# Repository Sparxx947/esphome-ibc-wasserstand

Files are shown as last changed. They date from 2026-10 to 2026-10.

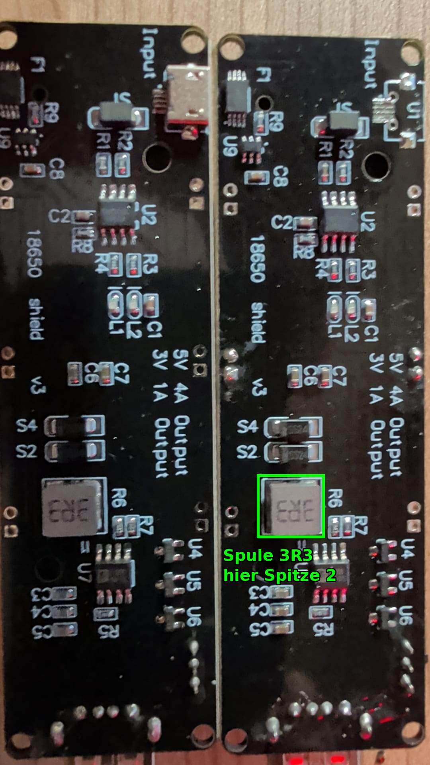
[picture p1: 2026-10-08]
fotos/shield-rueckseite-spule.jpg

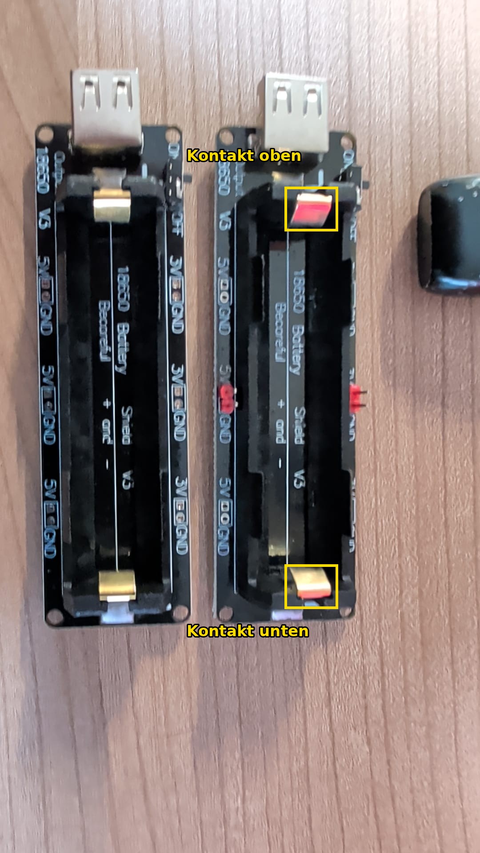
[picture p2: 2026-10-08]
fotos/shield-vorderseite-kontakte.jpg

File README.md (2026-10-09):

🇬🇧 [English version](README.en.md)

# IBC-Wasserstand und Überlaufschutz (ESPHome + Home Assistant)

Füllstandsmessung für einen 1000-l-IBC-Regenwassercontainer mit Pumpensteuerung, damit er nicht überläuft.
Zwei ESPHome-Knoten auf Wemos D1 mini, die Pumpenlogik läuft in Home Assistant.

> **Stand: 08.10.2026.** Quellen: Projektnotizen (04.–08.10.2026), Firmware aus dem ESPHome Builder, SCAD-Dateien, HA-Paketentwurf.
> Was nicht gemessen oder bestätigt ist, steht als *(ungeprüft)* oder *(Annahme)* im Text.

> **Nachbauen:** Die Dateien bilden eine konkrete Anlage ab. Vor eigener Verwendung:
> - Eigene `secrets.yaml` aus [`firmware/secrets.example.yaml`](firmware/secrets.example.yaml) anlegen (WLAN, API-Schlüssel, Fallback-AP-Passwörter).
> - In [`firmware/ibc-b.yaml`](firmware/ibc-b.yaml) unter `manual_ip` eine eigene feste IP eintragen (IP, Gateway, Subnetz, DNS) oder den `manual_ip`-Block entfernen, dann gilt DHCP.
> - In [`ha/ibc-pumpe.yaml`](ha/ibc-pumpe.yaml) die Entitäten-IDs an die eigene Anlage anpassen (Pumpen-Steckdose, Leistungssensor, ESPHome-Entitäten) und `notify.mobile_app_dein_handy` durch den eigenen Notify-Dienst ersetzen.
> - `abstand_leer_mm` / `abstand_voll_mm` (Knoten A) und `adc_faktor` (Knoten B) selbst einmessen, siehe [`docs/einmessen.md`](docs/einmessen.md).

---

## 1. Kurzbeschreibung

**Aufbau vor Ort:** Drei IBC-Container (je 1000 l, auf Palette) stehen ebenerdig draußen unter einem Dach.

| Container | Rolle | Was dort sitzt |
|---|---|---|
| **A** | Sammelbehälter. Zulauf von oben über ein HT-Rohr DN50 (Regenrinne) | Tauchpumpe mittig am Boden (Steigrohr ragt aus dem Einfüllstutzen), **Knoten A `ibc-wasser`** mit Ultraschallsensor auf der Oberseite |
| **B** | Zielbehälter, 2–3 m höher angefahren | **Knoten B `ibc-b`** (Solar, Tiefschlaf) mit Schwimmerschalter im Einfüllstutzen |
| **C** | Zielbehälter | unten per Schlauch mit B verbunden, steht daher gleich hoch wie B, braucht keinen eigenen Sensor |

**Prinzip:**

1. **Knoten A** misst mit einem wasserdichten Ultraschallsensor (A02YYUW, UART) von oben den Abstand zur Wasseroberfläche
   und rechnet daraus Füllstand in % und Inhalt in Litern. Ein IBC ist annähernd ein Quader, deshalb ist die Umrechnung linear
   (≈ 10 l pro cm).
2. **Knoten B** meldet über einen Schwimmerschalter, ob B/C voll sind. Er läuft auf einem 18650-Akku mit kleinem Solarpanel,
   wacht alle 15 min auf und bleibt wach, solange die Pumpe läuft.
3. **Home Assistant** schaltet die vorhandene Pumpe in A über eine Zigbee-Steckdose mit Leistungsmessung:
   an bei A ≥ 90 %, aus bei A ≤ 70 %, sofort aus bei „Ziel voll“. Dazu kommen Sicherungen gegen Trockenlauf, zu lange Laufzeit,
   Ausfall der Sensoren und ein stummer Knoten B.

**Ausfallrichtung:** Ein offener Schwimmereingang, also auch ein abgerissenes Kabel, gilt als „Ziel voll“ und sperrt die Pumpe.
Meldet sich Knoten B nicht, startet die Pumpe nicht. Nach einem Stromausfall bleibt die Steckdose aus.

---

## 2. Status (Stand 09.10.2026)

| Bereich | Status | Datum / Hinweis |
|---|---|---|
| Ultraschallsensor A02YYUW | ✅ geliefert, am Tisch getestet (Zimmerdecke 1,37–1,47 m, Hand sofort erkannt) | 06.10. |
| Knoten A geflasht, im Builder und in HA | ✅ fertig | 06.10. ~20:15 |
| Kombi-Gehäuse A (Sensor + D1 mini) | ✅ gedruckt (2. Fassung, siehe Abschnitt 5) | 07.10. |
| Kabelverschraubungen M12 | 🟡 bestellt (Amazon), Lieferung Fr 09.10.; werden mit Heißkleber eingeklebt | 09.10. 18:00 |
| Montage A auf dem IBC + Einmessen | ⬜ offen | bis 22.10. |
| Schwimmer-Eingang aus Firmware A entfernen | ⬜ offen (beim Einmessen) | — |
| Pumpen-Steckdose (Nous Zigbee) | ✅ in HA, Power-outage-memory = off; **zurzeit ausgesteckt** | 07.10. |
| Knoten B geflasht (feste IP), im Builder und in HA | ✅ fertig, „wach halten“/Tiefschlaf getestet | 07.10. ~21:30–21:45 |
| Knoten B Innenverdrahtung (D0–RST, A0-Teiler, Schwimmer) | ✅ fertig, Tischtest Schwimmer bestanden | 08.10. 17:32 |
| Schwimmerhalter B | ✅ gedruckt | 08.10. |
| Gehäuse B | ⬜ druckfertig, noch nicht gedruckt | — |
| Deckeldichtung B (TPU) | ✅ konstruiert, Kollision geprüft; ⬜ nicht gedruckt | 09.10. |
| Deckelschrauben B 3 × 12 | ⬜ fehlen, kaufen | — |
| Akku B | 🟡 E-Zigarettenakku im Selbstentladetest (Bezug 4,137 V) | Bewertung 09.10. 14:30 |
| Solarpanel, Z-Diode, EVE-Akku, Panelkabel | ⬜ nicht bestellt, reichelt-Bestellung geplant | 02.11. |
| HA-Pumpenpaket `ha/ibc-pumpe.yaml` | ⬜ Entwurf, **nicht eingespielt** (in HA existiert noch keine IBC-Automation) | — |
| Pumpen-Normalleistung, Trockenlauf-Schwelle | ⬜ offen, erst beim ersten Pumpenlauf messbar | — |

---

## 3. Stückliste

Preise und Artikelnummern nur dort, wo sie in den Notizen belegt sind. „—“ = nicht notiert.

### Knoten A (`ibc-wasser`, Container A)

| Teil | Menge | Bezeichnung / Typ | Bezugsquelle, Art.-Nr., Preis | Status |
|---|---|---|---|---|
| Mikrocontroller | 1 | Wemos D1 mini V3.0.0 (ESP8266, USB-Seriell CH340) | Bestand (früheres WLAN-Testgerät) | vorhanden, geflasht |
| Ultraschallsensor | 1 | A02YYUW-Typ, UART 9600, 3–450 cm, wasserdicht (IP67), 60° Abstrahlwinkel; Rechteckgehäuse 84,6 × 29,6 × 18,5 mm (Datenblatt DFRobot SEN0311), Kabel ~32 cm mit JST-PH-Stecker | Amazon B0CM1F4KFS, 21,95 € | geliefert 06.10. |
| Gehäuse + Deckel | 1 + 1 | `ibc_kombi_gehaeuse.stl` + `ibc_kombi_deckel.stl` | Eigendruck, PETG | gedruckt 07.10. |
| Kabelverschraubung | 2 | M12, Klemmbereich 3–6,5 mm, IP67, schwarz (Seki, 10er-Pack, für A und B) | Amazon B083V8V9TR, 5,49 € / 10 Stk | bestellt, Lieferung 09.10. |
| Blechschrauben Befestigung | 4 | Edelstahl 4,2 × 16 (im IBC 3,2 mm vorbohren) | — | *ungeklärt* |
| Blechschrauben Deckel | 4 | 3 × 16 | — | *ungeklärt* |
| Dichtband | 1 | zwischen Flansch und IBC-Oberseite | — | *ungeklärt* |
| Silikon | etwas | Raupe unter dem Sensor und im Kabelschlitz der Trennwand | — | *ungeklärt* |
| Heißkleber | etwas | Gegenmuttern der M12-Verschraubungen innen sichern | — | vorhanden *(Annahme)* |
| Stromversorgung | 1 | langes USB-Kabel, an 5V/G des D1 mini angelötet, plus USB-Netzteil | — | *ungeklärt* |
| Kabelbinder | einige | optional zusätzlich an der Käfigstrebe | — | — |

### Knoten B (`ibc-b`, Container B)

| Teil | Menge | Bezeichnung / Typ | Bezugsquelle, Art.-Nr., Preis | Status |
|---|---|---|---|---|
| Mikrocontroller | 1 | Wemos D1 mini (ESP8266, CH340) | Bestand | vorhanden, geflasht |
| Akku-Shield | 1 | „18650 Battery Shield V3“, **rechte Ausführung** (Input-Buchse U1 nicht bestückt, Diode SS24 vorhanden). Bestückung vermutlich TC4056A + DW01/8205 + FP6298 *(nach Layout abgeleitet, Aufdrucke unlesbar)* | Bestand | vorhanden, Polung geprüft |
| Akku (Variante 1) | 1 | 18650 aus einer E-Zigarette, vermutlich ungeschützte Hochstromzelle | Bestand | im Selbstentladetest bis 09.10. |
| Akku (Variante 2) | 1 | EVE 18650-33V, Flat-Top | reichelt, 6,82 € | nicht bestellt (02.11.) |
| Solarpanel | 1 | Seeed DEBO SOLAR 1.0W, 5,5 V / ~170 mA, **Leerlauf bis 8,2 V** | reichelt, 6,20 € (lieferbar ab 23.10.) | nicht bestellt (02.11.) |
| Z-Diode | 2 (1 + Reserve) | BZX 85C6V2, 6,2 V / 1,3 W | reichelt, 0,06 €/Stk | nicht bestellt (02.11.) |
| Panelkabel | ~3 m | H05RN-F 2 × 0,75 mm² (außen) | reichelt, — | nicht bestellt (02.11.) |
| Widerstände | 2 | 100 kΩ + 22 kΩ in Reihe (gemessen zusammen 121,5 kΩ) | Sortiment | eingebaut 08.10. |
| Drahtbrücke | 1 | D0 (GPIO16) → RST, für den Tiefschlaf | — | eingebaut 08.10. |
| Schwimmerschalter | 1 | seitlicher Einbau-Schwimmer mit Klappschwimmer (Reed, 2 Adern, ~3 mm Kabel), Gewinde Ø 19 mm × 19,5 mm, Dichtring + Mutter; Pfeil am Körper = Einbaulage | Bestand | vorhanden |
| Schwimmerhalter | 1 | `ibc_schwimmer_halter.stl` | Eigendruck, PETG | gedruckt 08.10. |
| Gehäuse + Deckel | 1 + 1 | `ibc_b_gehaeuse.stl` + `ibc_b_deckel.stl` (außen 130 × 74 × 32 mm + Laschen) | Eigendruck, PETG | druckfertig, nicht gedruckt |
| Kabelverschraubung | 2 | M12 aus dem Seki-Pack (s. o.): Schwimmer + Panel | s. o. | bestellt |
| Schrauben Deckel | 4 | 3 × 12, Blech- **oder** Spanplattenschraube (beißt in PETG-Dome mit 2,5-mm-Loch), Edelstahl A2 oder verzinkt | — | fehlen, kaufen |
| Deckeldichtung | 1 | `ibc_b_dichtung.stl`, TPU 95A (~2,8 g). Alternative: selbstklebendes EPDM-Moosgummiband ~3 mm breit, 2–3 mm dick | Eigendruck | konstruiert 09.10., nicht gedruckt |
| Klemme innen | 1 | Schraubklemme/Stecker für Schwimmer und Panel (Verlängerung innen im Gehäuse, nicht draußen) | — | offen |
| Befestigung | — | Kabelbinder (bis 5 mm) oder Schraube 4 mm durch die Laschen an den Käfig | — | — |
| Externe Antenne | — | erst, wenn der WLAN-Test am Standort schlecht ist (Reserve: D1 mini Pro mit Antennenbuchse) | — | bewusst nicht gekauft |

### Pumpe, Steckdose, Sonstiges

| Teil | Menge | Bezeichnung / Typ | Bezugsquelle, Preis | Status |
|---|---|---|---|---|
| Pumpe | 1 | vorhandene Tauchpumpe in A, Steigrohr → Edelstahl-Wellschlauch → Kugelhahn → Gartenschlauch zu B/C. Typ/Leistung **unbekannt** | Bestand | vorhanden |
| Zigbee-Steckdose | 1 | Nous Smart Plug mit Leistungsmessung (Zigbee2MQTT). **Innengerät** → unter Dach bzw. in Schutzbox | Bestand | vorhanden, zurzeit ausgesteckt |
| Verbindung B ↔ C | 1 | Schlauch unten zwischen B und C | Bestand | vorhanden |
| Multimeter | 1 | UNI-T UT139C (µA-Bereich, für Ruhestrom und ADC-Abgleich) | Amazon B00KKLW35O, 49,50 € | bestellt, Lieferung 09.10. |
| Filament | — | PETG (ASA bei direkter Sonne) | Bestand | vorhanden |

> Die alternative 4× Hilpress ECO 50010 aus dem ersten reichelt-Korb ist durch das Seki-Pack ersetzt.
> Die Farbe der Seki-Lieferung ist unsicher: Der Shop beschreibt auch die Variante „Schwarz“ als „grau (RAL7035)“.

---

## 4. Pinbelegung und Verdrahtung

### Knoten A (`ibc-wasser`)

| Von | Ader / Signal | D1 mini | GPIO | Hinweis |
|---|---|---|---|---|
| A02YYUW | rot, VCC | 3V3 | — | an 3,3 V liegt auch der TX-Pegel bei 3,3 V, also ESP-sicher |
| A02YYUW | schwarz, GND | G | — | |
| A02YYUW | weiß, TX (Sensor sendet) | D7 | GPIO13 | UART RX, 9600 Bd, Paket alle ~100 ms: `0xFF, Hi, Lo, Summe` |
| A02YYUW | gelb, RX / Modus | **frei lassen** | — | auf Masse schaltet der Sensor in einen anderen Ausgabemodus |
| USB-Netzteil | +5 V / GND | 5V / G | — | Kabel angelötet, durch eine M12-Verschraubung |
| ~~Schwimmer~~ | ~~2 Adern~~ | ~~D5 + G~~ | ~~GPIO14~~ | **entfällt**, der Schwimmer sitzt jetzt an Knoten B. Steht noch in der Firmware und wird beim Einmessen entfernt |

Die Aderfarben stammen aus dem Werkstattbuch und sind gegen den gelieferten Sensor nicht gesondert dokumentiert. Vor dem Anlöten bitte nachsehen.

### Knoten B (`ibc-b`) – Schaltplan: [`plaene/ibc-b-schaltplan.pdf`](plaene/ibc-b-schaltplan.pdf)

| Von | Nach | Hinweis |
|---|---|---|
| Solarpanel + | Z-Diode Kathode (Ring) → Shield-Pads U1 **VBUS** | Z-Diode **parallel** zum Eingang. Vor dem Löten Foto der Pads machen und klären, welches Pad VBUS ist |
| Solarpanel − | Z-Diode Anode → Shield-Pads U1 **GND** | |
| Shield **5V** | D1 mini **5V** | **Nicht** den 3V-Ausgang des Shields nehmen (XC6206 ohne Ausgangskondensator, instabil) |
| Shield GND | D1 mini G | |
| Akku + (Halterkontakt, Draht angelötet) | 100 kΩ + 22 kΩ in Reihe → **A0** | mit dem internen Teiler 220k/100k des D1 mini ergibt sich ein Endwert von ~4,4 V und ein Dauerstrom von ~10 µA |
| D0 (GPIO16) | RST | Drahtbrücke für das Aufwachen aus dem Tiefschlaf |
| Schwimmer Ader 1 | D5 (GPIO14) | interner Pull-up |
| Schwimmer Ader 2 | G | |
| — | GPIO2 | blaue Status-LED auf dem Modul |

**Schaltlogik Schwimmer B:** eingebaut so, dass er **bei Wasser öffnet**. Geschlossen heißt „Wasser unten“, `Zielcontainer voll` = aus.
Offen heißt „B voll“ **oder** „Kabel ab“, `Zielcontainer voll` = an, die Pumpe ist gesperrt.

**Niemals D1-USB und Shield gleichzeitig anschließen.**

### Weitere Pläne

- [`plaene/ibc-messblatt.pdf`](plaene/ibc-messblatt.pdf) / `.html`: Messblatt vom 06.10. Es ist **teilweise überholt**: Es geht noch von einem runden
  Sensorkopf im Schraubdeckel und dem Schwimmer an A aus. Die Felder 4–6 (Einmessen) gelten weiter, sinngemäß für die neue Sensorstelle.
- [`plaene/ibc_b_plan.py`](plaene/ibc_b_plan.py): Quelle des Schaltplans B (matplotlib). Neu erzeugen mit `python3 ibc_b_plan.py ausgabe.pdf`.

---

## 5. Gehäuse

Quellen: [`gehaeuse/ibc-gehaeuse.scad`](gehaeuse/ibc-gehaeuse.scad) (A und Schwimmerhalter) und
[`gehaeuse/ibc-b-gehaeuse.scad`](gehaeuse/ibc-b-gehaeuse.scad) (Knoten B). In OpenSCAD `TEIL = "..."` setzen, F6, als STL exportieren.

| STL | Wofür | Status | Bemerkung |
|---|---|---|---|
| `ibc_kombi_gehaeuse.stl` | **A:** Sensor und D1 mini in einem Gehäuse, 111 × 99 × 28 mm inkl. Flansch | gedruckt 07.10. (2. Fassung) | zwei Kammern, Trennwand mit Kabelschlitz; Fenster 60 × 25 nach unten mit 45°-Aufweitung; 4 Löcher Ø 4,4 im Flansch; 2× M12 in der Außenwand der D1-Kammer; 2-mm-Kondenswasserloch |
| `ibc_kombi_deckel.stl` | Deckel zu A | gedruckt | Lippe gegen Schlagregen, 2 Druckrippen auf dem Sensorrücken (0,4 mm Vorspannung). Druck: Deckelplatte unten |
| `ibc_schwimmer_halter.stl` | **B:** hängt am Einfüllstutzen, trägt den Schwimmerschalter | gedruckt 08.10. | Steg 32 breit/5 dick, Haken über Stutzenwand 11,1 + 0,8 Luft, Loch Ø 19,5 in 120 mm Tiefe, Platte dort 6 mm; Kabelschlitze für Kabelbinder. Flach liegend drucken |
| `ibc_b_gehaeuse.stl` | **B:** Shield + D1 mini | druckfertig, **nicht gedruckt** | außen 130 × 74 × 32 + Laschen, Wand 3 mm, 2× M12 in der **unteren** Stirnwand, Ablauf Ø 2,5, Leisten für Shield (99,28 × 29,46, USB 6,74, Höhe 25 – gemessen) und D1, Klemmleiste für die Widerstände |
| `ibc_b_deckel.stl` | Deckel zu B | druckfertig | Lippe, 4× Blechschraube 3 × 12. Druck: Deckelplatte unten |
| `ibc_b_dichtung.stl` | Deckeldichtung zu B (TPU) | konstruiert 09.10., nicht gedruckt | Rahmen 1,6 mm auf der 3-mm-Wandoberkante, Wulst 0,8 × 0,6 auf Wandmitte, 4 Eckohren Ø 7,4 mit Loch Ø 3,4 über den Domen. Druck: TPU 95A, liegend (Wulst oben), 100 % Füllung, ~20 mm/s |
| `ibc_sensor_halter.stl`, `ibc_sensor_abdeckung.stl` | Einzelhalter für den Sensor (Flansch 104 × 60) | **ersetzt** durch das Kombi-Gehäuse | nicht mehr drucken |
| `vorschau_ibc.png` | Vorschaubild | **veraltet** | zeigt noch den runden Flansch und die alte D1-Box |

Im SCAD stehen außerdem `d1_box`/`d1_deckel` (getrennte D1-Box). Sie sind durch das Kombi-Gehäuse ersetzt.

**Material und Druck:** PETG (ASA bei direkter Sonne), 0,2 mm Schicht, ohne Stützen. Der Standort ist draußen, aber überdacht.
Füllung und Wandzahl sind für IBC nicht notiert (bei der Optolink-Box waren es 3 Wände).

**Bestückung A:**
1. M12-Verschraubungen von außen eindrehen. Die Gegenmutter innen so weit wie möglich aufdrehen, die Fläche anrauen und entfetten, dann innen rundum mit Heißkleber sichern.
   Grund: Im gedruckten Teil ist die Wand an den Bohrungen 6,4 mm dick, und die Standard-Verschraubung fasst nur ~3 mm.
   Die aktuelle SCAD/STL hat innen eine Ø-22-Aussparung auf 3 mm Restwand. Bei einem Neudruck entfällt das Einkleben.
2. Sensor mit einer **Silikonraupe** auf den Auflagerand des Fensters setzen. Die Laschen bleiben frei, die Kabeltülle läuft durch den Schlitz der Trennwand, den Schlitz ebenfalls mit Silikon schließen.
   Das hält die feuchte Tankluft aus der D1-Kammer fern.
3. D1 mini auf die Auflageleisten der D1-Kammer, mit Doppelklebeband oder Heißkleber fixieren.
4. USB-Kabel durch eine Verschraubung, an 5V/G anlöten. Die zweite Verschraubung bleibt frei bzw. ist Reserve.
5. Deckel mit 4 Blechschrauben 3 × 16.

**Bestückung B:** Shield auf die Längsleisten (14 mm Mutterzone vor den Verschraubungen frei lassen), D1 mini daneben mit dem Antennenende **nach oben**, weg von Akku und Käfig.
Widerstände in die Klemmleiste. Schwimmer und Panel durch die beiden M12 unten, Verlängerungen nur innen an einer Klemme.
Einbaulage: hängend, Verschraubungen nach unten, Deckel nach vorn.

**Dichtung B:** TPU-Rahmen mit dem Wulst nach oben auf den Gehäuserand legen, Deckel darauf, die 4 Schrauben 3 × 12 über Kreuz
gleichmäßig anziehen, bis der Wulst gequetscht ist (nicht überdrehen, sonst reißen die Dome). Mit Deckel 2,4 mm und Dichtung ~2 mm
greift eine 12-mm-Schraube noch ~7,5 mm im Dom. Die Dichtung ist innen frei für die Deckellippe (0,35 mm Luft, an den Eckohren 0,3 mm).
Statt der gedruckten Dichtung geht auch selbstklebendes EPDM-Moosgummiband (~3 mm breit) auf der Wandoberkante.
**Kein essigvernetzendes Silikon** (Bad-Silikon) im Gehäuse: Es gast Essigsäure aus und lässt Kontakte korrodieren. Wenn Silikon,
dann neutralvernetzend und nur für Fugen, die zu bleiben (nicht den Deckel verkleben).

**Lehren aus der Konstruktion:**
- Der Sensor ist **kein** runder Kopf, sondern ein Rechteckgehäuse mit zwei Wandlern und zwei Laschen. Die anfängliche Annahme Ø 24,5 war falsch, die Halter wurden neu konstruiert.
- Ein Fenster für beide Wandler statt zweier Löcher: Dann spielt der Wandlerabstand keine Rolle.
- Vor dem STL-Export Kollisionen prüfen: Deckellippe gegen Trennwand (Aussparung nötig), Muttern gegen Wandstärke, Domschrauben gegen Lippe.
  Für die Dichtung B per Schnittmenge belegt (`TEIL = "pruef_gehaeuse"` / `"pruef_deckel"` exportieren und das Volumen messen):
  Gehäuse 0 mm³ (nur Berührung), Deckel nur der Wulst (~186 mm³ = gewollte Quetschung).
- Kreise, die eine Kante nur tangential berühren, ergeben ein nicht-manifoldes Netz (Slicer-Warnung). Deshalb überlappen die Eckohren 0,2 mm in die Wand.
  Beim Kombi-Gehäuse sind nur Berührflächen übrig.
- Wandstärke an Verschraubungen: Standard-M12 hat ~8–9 mm Gewinde, die Wand darf samt Mutter höchstens ~3 mm dick sein.
- Die Gewindelänge der Seki-Verschraubungen ist im Angebot nicht angegeben. Nach Lieferung messen, dann ggf. `k_m12_wand` im SCAD anpassen.

---

## 6. Firmware

| | Knoten A | Knoten B |
|---|---|---|
| Datei | [`firmware/ibc-wasser.yaml`](firmware/ibc-wasser.yaml) | [`firmware/ibc-b.yaml`](firmware/ibc-b.yaml) |
| Gerätename / Friendly | `ibc-wasser` / „IBC Wasser“ | `ibc-b` / „IBC B“ |
| Board | `d1_mini` (ESP8266) | `d1_mini` (ESP8266) |
| IP | 192.168.178.189 (DHCP, in der FRITZ!Box fest reserviert) | 192.168.178.196 (`manual_ip` in der YAML **und** in der FRITZ!Box reserviert) |
| Hostname | `ibc-wasser.local` | `ibc-b.local` |
| Fallback-AP | `IBC-Fallback` | `IBC-B-Fallback` (2 min Timeout) |
| Secrets | `wifi_ssid`, `wifi_password`, `ibc_api_key`, `ibc_ap_password` | `wifi_ssid`, `wifi_password`, `ibc_b_api_key`, `ibc_b_ap_password` |

Die Dateien in `firmware/` sind der Stand aus dem **ESPHome Builder**, und der Builder ist führend.
Eine lokale Arbeitskopie von A hat bereits `abstand_voll_mm: "50"`. Im Builder steht noch `80`, nachgezogen wird das beim Einmessen.

### Wichtige Substitutions

**A (`ibc-wasser`)**

| Name | Wert | Bedeutung |
|---|---|---|
| `abstand_leer_mm` | `1050` (Platzhalter) | Abstand Sensor → Boden = 0 %. **Einmessen** |
| `abstand_voll_mm` | `80` (Builder), Ziel `50` | Abstand Sensor → höchster Stand = 100 %. 100 % = 50 mm unter der IBC-Oberseite, weil A keinen Überlauf hat |
| `volumen_l` | `1000` | Nennvolumen, lineare Umrechnung |

Filter: `filter_out: nan` → Median (Fenster 15, alle 10 Werte, erster nach 5) → `throttle: 30s`. Damit fallen einzelne Fehlechos von Wand oder Tropfen weg.

**B (`ibc-b`)**

| Name | Wert | Bedeutung |
|---|---|---|
| `schlaf` | `15min` | Tiefschlaf zwischen zwei Meldungen |
| `schlaf_akku_schwach` | `120min` | bei Akku < `akku_schwach_v` |
| `akku_schwach_v` | `3.3` | Schwelle für den Sparbetrieb |
| `adc_faktor` | `4.42` | (122k + 220k + 100k)/100k. Mit dem gemessenen 121,5 kΩ wären es 4,415. **Gegen Multimeter abgleichen** |
| `pumpe` | `switch.steckdose_ibc_wassercontainer_pumpe` | läuft die Pumpe, bleibt B wach |
| `wach_halten` | `input_boolean.ibc_b_wach_halten` | Helfer für OTA und Tests |
| `einrichtung_dauer` | `10min` | Einrichtungsfenster nach Strom/Reset (nicht nach Tiefschlaf) |
| `max_wach` | `3000` s | spätestens nach 50 min trotzdem schlafen |

Ablauf B: aufwachen → WLAN mit fester IP (`fast_connect`) → nach der API-Verbindung 3 s auf die Zustände von Pumpe und „wach halten“ warten →
Akku messen und melden → schlafen oder wach bleiben. Notbremse: `run_duration: 30s`, wenn HA nicht erreichbar ist. `reboot_timeout: 0s`.

### Entitäten in Home Assistant (geprüft 08.10.2026)

| Knoten | Entität | Bedeutung |
|---|---|---|
| A | `sensor.ibc_wasser_abstand_wasser` | Rohabstand in mm (Diagnose) |
| A | `sensor.ibc_wasser_fullstand` | Füllstand % |
| A | `sensor.ibc_wasser_inhalt` | Inhalt in L |
| A | `sensor.ibc_wasser_wlan_signal`, `sensor.ibc_wasser_laufzeit` | Diagnose |
| A | `binary_sensor.ibc_wasser_zielcontainer_voll` | **Altlast**, verschwindet mit dem Entfernen des Schwimmers aus der Firmware A |
| B | `binary_sensor.ibc_b_zielcontainer_voll` | an = Schwimmer offen = B voll oder Kabel ab |
| B | `sensor.ibc_b_akku` | Akkuspannung V, `force_update` = Lebenszeichen (`last_reported`) |
| B | `sensor.ibc_b_akku_ladung` | grob linear 3,3 V = 0 % … 4,15 V = 100 % |
| B | `sensor.ibc_b_wlan_signal`, `sensor.ibc_b_wach_seit` | Diagnose |
| HA | `input_boolean.ibc_b_wach_halten` | UI-Helfer (angelegt 07.10.) |
| Zigbee | `switch.steckdose_ibc_wassercontainer_pumpe`, `sensor.steckdose_ibc_wassercontainer_pumpe_power` | Pumpe und Leistung |

### Secrets

`firmware/secrets.example.yaml` ist nur eine Vorlage. **Echte Werte stehen ausschließlich im ESPHome Builder** (`secrets.yaml`) und nie im Repo.
`.gitignore` schließt `secrets.yaml` und `secrets.*.yaml` aus. API-Schlüssel erzeugen: `openssl rand -base64 32`.

### Flashen

- **Normalfall: Builder, OTA.** YAML im Builder ändern → *Install* → *Wirelessly*.
  - Bei **B** vorher in HA `IBC B wach halten` einschalten und bis zum nächsten Aufwachen warten (max. 15 min, bei schwachem Akku bis 2 h).
    Danach wieder ausschalten, sonst bleibt B wach und leert den Akku.
- **Erstflash per USB** (am PC, Container `ghcr.io/esphome/esphome:<version>`), immer mit `esphome run <datei>.yaml --device /dev/ttyUSB0` **und den echten Secrets**.
  Im Log auf „Successfully compiled“ achten und danach per API mit dem echten Schlüssel gegenprüfen.
  Bei B: Klappt das Flashen per USB nicht, die D0–RST-Brücke kurz abziehen.
- ⚠️ **Falle:** **Nie einen Prüfbuild mit Dummy-Secrets flashen.** `esphome upload` kompiliert nicht neu, sondern nimmt blind den letzten Build aus `.esphome/`.
  So landeten am 06.10. bei einem anderen Projekt Dummy-Hotspot-Passwort und falscher API-Schlüssel auf dem Gerät. Prüfbuilds danach löschen.

---

## 7. Anleitungen

Die ausführlichen Schritt-für-Schritt-Anleitungen stehen in `docs/`:

| Anleitung | Inhalt |
|---|---|
| [`docs/einbau.md`](docs/einbau.md) | Aufbau, Inbetriebnahme am Tisch, Montage A und B vor Ort, Pumpe, Test |
| [`docs/einmessen.md`](docs/einmessen.md) | **Einmessen A** (leer/voll, Formeln, Builder), ADC-Abgleich B, Akkutest, Pumpen-Normalleistung und Trockenlauf-Schwelle, Schwimmer-Schaltrichtung |
| [`docs/fehlersuche.md`](docs/fehlersuche.md) | bekannte Fehlerbilder mit Ursache und Lösung |
| [`docs/verlauf.md`](docs/verlauf.md) | Projektverlauf 04.–08.10.2026 und Entscheidungen |

Kurzfassung Einmessen A (Details in `docs/einmessen.md`):

```
abstand_leer_mm = Sensorwert "Abstand Wasser" (mm) + Wassertiefe mit Zollstock an der Öffnung (mm)
abstand_voll_mm = 50                     (100 % = 50 mm unter der IBC-Oberseite)
Füllstand %     = (leer − Abstand) / (leer − voll) × 100     (auf 0…100 begrenzt)
Inhalt L        = Füllstand % / 100 × 1000
```

---

## 8. Home-Assistant-Anbindung

Datei: [`ha/ibc-pumpe.yaml`](ha/ibc-pumpe.yaml), **Entwurf, noch nicht eingespielt**. Es ist ein HA-Paket mit `input_boolean.ibc_pumpe_gesperrt`,
`input_number.ibc_a_startstand` und 9 Automationen. Push geht nur an Jens' Handy (`notify.mobile_app_dein_handy`).

| Automation | Auslöser | Wirkung |
|---|---|---|
| `ibc_pumpe_ein` | A > 90 % **oder** B meldet sich (neuer Akkuwert) | Pumpe an, wenn A > 90 %, B-Meldung < 120 s alt, Ziel nicht voll, keine Sperre und Pumpe aus. Merkt den Startstand |
| `ibc_pumpe_aus_normal` | A < 70 % | Pumpe aus |
| `ibc_pumpe_aus_ziel_voll` | Ziel voll → an | Pumpe aus + Push |
| `ibc_pumpe_sicherung` | 30 min Laufzeit / Leistung < 20 W für 20 s / nach 10 min weniger als 2 % gesunken | aus + **Sperre** + Push mit Grund |
| `ibc_sensor_ausfall` | Füllstand A 15 min `unavailable` | Pumpe aus + Push |
| `ibc_pumpe_aus_b_stumm` | Pumpe an und B > 180 s ohne Meldung bzw. Schwimmer unavailable | Pumpe aus + Push |
| `ibc_b_lebenszeichen` | B > 40 min still | Push (Pumpe startet so lange nicht) |
| `ibc_b_akku_schwach` | Akku B < 3,4 V | Push |
| `ibc_a_uebervoll` | A > 97 % für 2 min | Push (A hat keinen Überlauf) |

Die Sperre wird **nur von Hand** gelöst: `IBC-Pumpe gesperrt` ausschalten.

**Vor dem Einspielen:**
1. Die Schwelle `below: 20` in `ibc_pumpe_sicherung` durch ~60 % der gemessenen Normalleistung ersetzen (siehe `docs/einmessen.md`).
2. Die Entitäten-IDs passen (geprüft 08.10.). `input_boolean.ibc_b_wach_halten` existiert schon als UI-Helfer und darf im Paket **nicht** noch einmal stehen.
3. Weg festlegen: als YAML-Paket (`packages:` in der HA-Konfiguration) oder die Automationen per UI/API anlegen. Das ist noch offen.
4. Pumpen-Steckdose wieder einstecken, Power-outage-memory muss `off` bleiben.

---

## 9. Offene Punkte, nächste Schritte, Termine

| Wann | Was | Wer |
|---|---|---|
| Fr 09.10. 14:30 | E-Zig-Akku Selbstentladetest: messen (außerhalb des Shields). Bezug 08.10. 14:25 = 4,137 V. ≥ 4,09 V gut, 4,04–4,09 grenzwertig, < 4,04 V aussortieren. Danach 3V/5V am rechten Shield messen | Jens |
| Fr 09.10. 18:00 | M12-Verschraubungen ins Kombi-Gehäuse A einkleben, Farbe der Lieferung prüfen, Gewindelänge und Mutterhöhe messen | Jens |
| nach Akkutest | Shield-5V + Akku an Knoten B, A0 gegen Multimeter abgleichen (`adc_faktor`) | Jens |
| — | Gehäuse B drucken | Jens |
| — | WLAN-Test am Standort B (D1 per Powerbank) → entscheidet über externe Antenne | Jens |
| bis 22.10. | A montieren (Ausschnitt 70 × 35, Blechschrauben 4,2 + Dichtband) und einmessen; Schwimmer aus der Builder-YAML A entfernen | Jens |
| bis 22.10. | Pumpe erstmals laufen lassen → Normalleistung; HA-Paket anpassen und einspielen | Jens |
| **23.10.–01.11.** | **Jens nicht zu Hause.** Keine Lieferungen, keine Handgriffe. Die Pumpenlogik darf in der Zeit nur laufen, wenn sie vorher getestet ist. Sonst bleibt die Steckdose ausgesteckt | — |
| Mo 02.11. 18:00 | reichelt bestellen: Seeed Solar 1 W, 2× BZX 85C6V2, EVE 18650-33V, H05RN-F 2 × 0,75 ~3 m. Vorher Preise und Lieferbarkeit neu prüfen (Stand 07.10. ~19–20 €) | Jens |
| nach Lieferung | Panel + Z-Diode an die U1-Pads (vorher Pad-Foto), Knoten B montieren, Schwimmerhalter einbauen | Jens |
| später | Schlafstrom über den Akkuspannungsverlauf in HA bewerten (keine µA-Messung geplant) | — |
| offen | Länge des Schwimmerkabels bis zum Gehäuse B (reicht sie nicht: innen mit H05RN-F verlängern) | Jens |
| offen | Abstand Steckdose ↔ Gehäuse A (USB-Kabellänge), Zigbee-Empfang am Standort | Jens |
| offen | Pumpentyp und Fördermenge (wichtig für die „10 min < 2 %“-Regel) | Jens |
| später, optional | zweiter A02YYUW für einen Füllstand in B (Konzept mit FireBeetle verworfen, zu teuer) | — |

---

## 10. Dateiübersicht

```
.
├── README.md                     diese Datei
├── README.en.md                  englische Fassung
├── .gitignore                    schließt secrets*.yaml, .esphome/, Backups aus
├── docs/                         jede Anleitung auch als <name>.en.md (Englisch)
│   ├── einbau.md                 Aufbau, Montage, Inbetriebnahme, Test
│   ├── einmessen.md              Kalibrieren A und B, Pumpenschwelle
│   ├── fehlersuche.md            bekannte Fehlerbilder
│   └── verlauf.md                Projektverlauf und Entscheidungen
├── firmware/
│   ├── ibc-wasser.yaml           Knoten A (Builder-Stand)
│   ├── ibc-b.yaml                Knoten B (Builder-Stand)
│   └── secrets.example.yaml      Vorlage, keine echten Werte
├── gehaeuse/
│   ├── ibc-gehaeuse.scad         Kombi-Gehäuse A, Schwimmerhalter, ältere Einzelteile
│   ├── ibc-b-gehaeuse.scad       Gehäuse Knoten B
│   ├── ibc_kombi_gehaeuse.stl    A – Gehäuse            (gedruckt)
│   ├── ibc_kombi_deckel.stl      A – Deckel             (gedruckt)
│   ├── ibc_schwimmer_halter.stl  B – Schwimmerhalter    (gedruckt)
│   ├── ibc_b_gehaeuse.stl        B – Gehäuse            (druckfertig)
│   ├── ibc_b_deckel.stl          B – Deckel             (druckfertig)
│   ├── ibc_b_dichtung.stl        B – Deckeldichtung TPU (konstruiert)
│   ├── ibc_sensor_halter.stl     ersetzt, nicht drucken
│   ├── ibc_sensor_abdeckung.stl  ersetzt, nicht drucken
│   └── vorschau_ibc.png          veraltete Vorschau
├── ha/
│   └── ibc-pumpe.yaml            HA-Paket Pumpenlogik (Entwurf)
├── plaene/
│   ├── ibc-b-schaltplan.pdf      Schaltplan Knoten B
│   ├── ibc_b_plan.py             Quelle des Schaltplans
│   ├── ibc-messblatt.pdf/.html   Messblatt 06.10. (teilweise überholt)
└── fotos/
    ├── ibc-sensorposition.jpg    vorgeschlagene Sensorstelle auf A (~35 cm zur Pumpe)
    ├── shield-vorderseite-kontakte.jpg
    └── shield-rueckseite-spule.jpg   Polungstest (+ piept an Spule 3R3)
```

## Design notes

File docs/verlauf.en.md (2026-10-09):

🇩🇪 [Deutsche Version](verlauf.md)

# Project history and decisions

Back to the [README](../README.en.md). Summarised from the project notes.

| Date | Event / decision |
|---|---|
| 04.10. | Idea: fill level A via ultrasound + existing float as "target full". Sensor A02YYUW ordered (JSN-SR04T rejected, blind ~20–25 cm at the top). Clarified: 3 containers at ground level, path to B/C 2–3 m high → existing pump. Pump via a free Zigbee plug with power metering. Firmware A and HA package designed and compiled (RAM 38.7 %, flash 40.5 %) |
| 06.10. | Sensor delivered. D1 mini flashed as `ibc-wasser` (.189, fixed assignment in the FRITZ!Box), in the Builder and in HA. Measurement sheet printed |
| 07.10. afternoon | Sensor measured: **rectangular housing**, not a round head → holder redesigned. Position in A clarified: pump centred in the neck, HT pipe in the neck → sensor **next to** the opening on the top surface. A has no overflow → 100 % = 50 mm below the top. Sensor cable only ~32 cm → **combined enclosure** sensor + D1 |
| 07.10. | Pump plug found (Nous, Z2M), power-outage memory → off. B and C are connected at the bottom → **one** float in B is enough. B is too far from A → **separate node**, preference for solar + battery |
| 07.10. | Expensive variant (FireBeetle 2 ESP32-C5 + panel + cells, ~€87) rejected ("must be possible cheaper"). **Budget variant:** existing D1 mini + existing 18650 Battery Shield V3 (right-hand one, without U1 jack) + 1 W panel + Zener diode. No wake-up by the float; instead HA only starts the pump on a fresh B report, and B stays awake as long as the pump is running |
| 07.10. | Float measured (thread 19, neck wall 11.1, switching height 120), B stays without a cap → float holder ready to print. Shield polarity checked on both shields. Combined enclosure A **printed** (2nd revision, wall at M12 6.4 mm) → hot glue instead of counterboring |
| 07.10. evening | Enclosure B, schematic B, firmware B finished. Node B **flashed** (.196 static), added to HA, helper `ibc_b_wach_halten` (keep awake) created, test keep awake / deep sleep ✔. The ESPHome Builder can be controlled via API. Amazon basket (multimeter UT139C, M12) ordered by Jens; remaining reichelt items postponed to **02.11.** (absence 23.10.–01.11.) |
| 08.10. | E-cig battery charged, reference value 4.137 V. 100 k + 22 k available. Float holder **printed**. Internal wiring B finished, bench test float ✔ (17:32) |
| 09.10. | **TPU lid gasket B** designed (`ibc_b_dichtung.stl`), collision checked by intersection, mesh cleaned. Lid screws 3 × 12 still missing |

## Rejected approaches

| Idea | Why not |
|---|---|
| Sensor in the screw cap of A | The HT pipe and the pump riser pipe sit in the neck, both within the sound cone |
| Stilling pipe DN110 with the sensor on top | not necessary, because the top surface next to the opening is flat and free |
| Drilling through the IBC wall (float) | hanging holder in the filler neck instead of drilling |
| Zigbee door contact as float node | Jens wanted a solar ESP with the later option of a fill level in B |
| FireBeetle 2 ESP32-C5/C6 | too expensive (total basket ~€87) |
| 6 V panel | open-circuit ~7.7 V > 6.5 V shield input |
| Shield 3V output for the D1 | XC6206 without output capacitor, unstable |
| µA measurement of the sleep current | replaced by observing the battery voltage curve in HA |

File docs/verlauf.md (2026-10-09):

🇬🇧 [English version](verlauf.en.md)

# Projektverlauf und Entscheidungen

Zurück zur [README](../README.md). Zusammengefasst aus den Projektnotizen.

| Datum | Ereignis / Entscheidung |
|---|---|
| 04.10. | Idee: Füllstand A per Ultraschall + vorhandener Schwimmer als „Ziel voll“. Sensor A02YYUW bestellt (JSN-SR04T verworfen, oben ~20–25 cm blind). Geklärt: 3 Container ebenerdig, Weg zu B/C 2–3 m hoch → vorhandene Pumpe. Pumpe über freie Zigbee-Steckdose mit Leistungsmessung. Firmware A und HA-Paket entworfen und kompiliert (RAM 38,7 %, Flash 40,5 %) |
| 06.10. | Sensor geliefert. D1 mini als `ibc-wasser` geflasht (.189, feste Zuordnung in der FRITZ!Box), im Builder und in HA. Messblatt gedruckt |
| 07.10. nachm. | Sensor vermessen: **Rechteckgehäuse**, kein runder Kopf → Halter neu. Lage in A geklärt: Pumpe mittig im Stutzen, HT-Rohr im Stutzen → Sensor **neben** die Öffnung auf die Oberseite. A hat keinen Überlauf → 100 % = 50 mm unter Oberseite. Sensorkabel nur ~32 cm → **Kombi-Gehäuse** Sensor + D1 |
| 07.10. | Pumpen-Steckdose gefunden (Nous, Z2M), Power-outage-memory → off. B und C sind unten verbunden → **ein** Schwimmer in B reicht. B ist zu weit von A → **eigener Knoten**, Wunsch Solar + Akku |
| 07.10. | Teure Variante (FireBeetle 2 ESP32-C5 + Panel + Zellen, ~87 €) abgelehnt („muss billiger gehen“). **Spar-Variante:** vorhandener D1 mini + vorhandenes 18650 Battery Shield V3 (rechtes, ohne U1-Buchse) + 1-W-Panel + Z-Diode. Kein Schwimmer-Wecken; dafür startet HA die Pumpe nur bei frischer B-Meldung, und B bleibt wach, solange die Pumpe läuft |
| 07.10. | Schwimmer vermessen (Gewinde 19, Stutzenwand 11,1, Schalthöhe 120), B bleibt ohne Deckel → Schwimmerhalter druckfertig. Shield-Polung an beiden Shields geprüft. Kombi-Gehäuse A **gedruckt** (2. Fassung, Wand an M12 6,4 mm) → Heißkleber statt Aussenken |
| 07.10. abends | Gehäuse B, Schaltplan B, Firmware B fertig. Knoten B **geflasht** (.196 fest), in HA aufgenommen, Helfer `ibc_b_wach_halten` angelegt, Test wach halten / Tiefschlaf ✔. ESPHome Builder lässt sich per API steuern. Amazon-Korb (Multimeter UT139C, M12) von Jens bestellt; reichelt-Rest auf **02.11.** verschoben (Abwesenheit 23.10.–01.11.) |
| 08.10. | E-Zig-Akku geladen, Bezugswert 4,137 V. 100 k + 22 k vorhanden. Schwimmerhalter **gedruckt**. Innenverdrahtung B fertig, Tischtest Schwimmer ✔ (17:32) |
| 09.10. | **TPU-Deckeldichtung B** konstruiert (`ibc_b_dichtung.stl`), Kollision per Schnittmenge geprüft, Netz bereinigt. Deckelschrauben 3 × 12 fehlen noch |

## Verworfene Wege

| Idee | Warum nicht |
|---|---|
| Sensor im Schraubdeckel von A | Im Stutzen sitzen HT-Rohr und Pumpensteigrohr, beides im Schallkegel |
| Schwallrohr DN110 mit Sensor obendrauf | nicht nötig, weil die Oberseite neben der Öffnung eben und frei ist |
| Durch die IBC-Wand bohren (Schwimmer) | Hängehalter im Einfüllstutzen statt Bohrung |
| Zigbee-Türkontakt als Schwimmerknoten | Jens wollte einen Solar-ESP mit späterer Option auf einen Füllstand in B |
| FireBeetle 2 ESP32-C5/C6 | zu teuer (Gesamtkorb ~87 €) |
| 6-V-Panel | Leerlauf ~7,7 V > 6,5 V Shield-Eingang |
| Shield-3V-Ausgang für den D1 | XC6206 ohne Ausgangskondensator, instabil |
| µA-Messung des Schlafstroms | ersetzt durch Beobachtung des Akkuspannungsverlaufs in HA |

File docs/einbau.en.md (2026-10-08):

🇩🇪 [Deutsche Version](einbau.md)

# Assembly, commissioning, installation and test

Back to the [README](../README.en.md). As of 08.10.2026. For calibration see [einmessen.en.md](einmessen.en.md).

---

## Part A: Node `ibc-wasser` (container A)

### A1. Bench assembly

1. Prepare the enclosure: glue in the M12 glands (see README section 5, Assembly A).
2. Connect the sensor: red → 3V3, black → G, white → D7, **yellow unconnected**.
   For testing, jumper wires go into the JST-PH connector (2 mm pitch); outdoors, soldering is better.
   The sensor cable is only ~32 cm long, which is why the D1 mini sits right next to it in the combined enclosure. Do **not** extend the cable. At UART 9600 it would work over several metres, but it is unnecessary.
3. Power cable: long USB cable through one gland, solder the wires to **5V** and **G**.
4. Bench function test: power on, watch `IBC Wasser Abstand Wasser` (water distance) in HA, hold the sensor up towards the room ceiling.
   In the test on 06.10. this gave 1.37–1.47 m, and a hand underneath was detected immediately.
5. Set the sensor into the window with a bead of silicone, seal the cable slot of the partition wall, fix the D1 mini.
   Only put the lid on after curing (4 × 3 × 16).

### A2. Location on the IBC

Photo with marking: [`fotos/ibc-sensorposition.jpg`](../fotos/ibc-sensorposition.jpg)

- on the IBC **top surface next to** the filler opening, **not** in the screw cap. That is where the HT pipe DN50 and the pump riser pipe sit
- front field between the two longitudinal struts of the steel cage, left of the vertical trough ("avoid the channel"), in front of the moulded lettering
- distance **≥ 30 cm from the pump** (estimated ~35 cm from the photo) and **≥ 20 cm from the side wall**, because of the 60° sound cone
- the spot is flat (Jens, 07.10.). Space required on the IBC ~111 × 99 mm. Jens measured whether that fits between the struts; a result is **not noted**

### A3. Mounting

1. Using the enclosure as a template, mark the **window at the bottom (68 × 33)** and cut an opening of **70 × 35 mm** into the IBC top surface.
   Fish the chips out of the container.
2. Mark the 4 flange holes, **pre-drill 3.2 mm** in the IBC.
3. **Sealing tape** under the flange. When brim-full, water reaches the flange, and PE is hard to glue.
4. Fasten with **4 stainless-steel self-tapping screws 4.2 × 16**. Nuts would not be reachable from the inside.
5. Optionally secure the cables with cable ties to the cage strut. USB power adapter into a socket under the roof.
6. Calibration → [einmessen.en.md](einmessen.en.md), section 1. At the same time remove the float block from firmware A.

---

## Part B: Node `ibc-b` (container B)

### B1. State of the internal wiring (08.10.)

Done and tested: D0–RST jumper, A0 divider (100 k + 22 k = 121.5 kΩ measured), float at D5/G. Schematic: [`plaene/ibc-b-schaltplan.pdf`](../plaene/ibc-b-schaltplan.pdf).

### B2. Battery and shield

1. Only insert the battery if it has passed the self-discharge test ([einmessen.en.md](einmessen.en.md), section 4).
2. Polarity: the marking on the holder is correct on **both** shields. Checked on 07.10.: "+" beeps against coil 3R3, "−" does not.
   A layout error with reversed holder polarity is known for this board series, so measure again with any other shield.
3. Insert the battery, then measure and note **5V/GND** and **3V/GND** on the shield.
4. Shield **5V → D1 5V**, **GND → G**. **No USB on the D1 mini at the same time.**
5. ADC calibration → [einmessen.en.md](einmessen.en.md), section 2.

### B3. Solar panel (after delivery from 02.11.)

1. Before soldering, take a **photo of the pads of the missing USB jack U1** and determine which pad is VBUS.
2. **Zener diode BZX 85C6V2 in parallel** with the input, **ring (cathode) to +**.
   Reason: the panel delivers up to 8.2 V open-circuit, and according to the vendor the shield input only tolerates 6.5 V. The panel is current-limited; the Zener diode only gets warm with a full battery and sunshine.
3. Panel cable H05RN-F 2 × 0.75 (~2–3 m) through the second M12 gland. The panel hangs **on the outside of the shed**.

### B4. Enclosure and mounting

1. Print enclosure B (`ibc_b_gehaeuse.stl` + `ibc_b_deckel.stl`).
2. Insert shield and D1 (antenna end facing up), resistors into the terminal strip.
3. Float and panel cables through the M12 at the bottom. If a cable is too short, extend it **inside** at a terminal, not outside.
4. Hang the enclosure **vertically** on the cage of B, glands **facing down**, lid facing forward. Fasten with cable ties through the tab slots or a 4 mm screw.

### B5. Installing the float

1. Float into the holder: thread through the 19.5 mm hole (plate 6 mm), sealing ring, nut. The thread is 19.5 mm long, leaving ~11 mm.
   **Mind the arrow** → switching direction "opens with water" ([einmessen.en.md](einmessen.en.md), section 3).
2. Cable with cable ties through the slots on the web.
3. Hang the holder with its hook over the rim of B's filler neck (neck wall 11.1 mm, inside 220.3 mm). The float points horizontally into the interior.
   **B stays without a cap**, because the outer leg of the hook sits over the thread.

### B6. Wi-Fi at the location

An outdoor AP is ~10 m away in line of sight. If problems are expected, test beforehand: D1 on a power bank at B, watch `IBC B WLAN-Signal` (Wi-Fi signal). On the PC it was −57 dBm, in HA most recently −55 to −63.
An external antenna (or a D1 mini Pro) is only bought if the result is poor.

---

## Part C: Pump and Home Assistant

1. Nous Zigbee plug under the roof or in a protective box, because it is an indoor device. Power-outage memory must stay **off**.
2. Plug in the pump, measure the normal power ([einmessen.en.md](einmessen.en.md), section 5).
3. Adapt `ha/ibc-pumpe.yaml` (power threshold) and deploy it (README section 8).

---

## Part D: Acceptance test

| # | Test | Expected result |
|---|---|---|
| 1 | Fill level A plausible (cross-check with folding rule) | deviation ≤ ~1 % |
| 2 | Node B reports regularly | `sensor.ibc_b_akku` new every ~15 min (`last_reported`) |
| 3 | Flip float B up (by hand) | "Zielcontainer voll" (target container full) on → with the pump running, immediately off + push. B is awake at this point because the pump is running. If B is asleep, this is only detected at the next wake-up |
| 4 | Disconnect the float cable | "voll" (full) = on, pump locked |
| 5 | Start the pump manually, power down node B | after > 180 s without a report: pump off + push |
| 6 | Run-time limit (shorten `for` in HA for testing) | after expiry off + lock + push; lock only released manually |
| 7 | Node A without power | after 15 min: pump off + push |
| 8 | Regular run A ≥ 90 % → ≤ 70 % | start at the next B wake-up, stop at 70 %, B sleeps again afterwards |
| 9 | Battery curve B over a few days | no steady decline in sunshine. Otherwise the quiescent current is too high, e.g. due to a bad shield batch |

Carry out tests 3–7 **before** the absence from 23.10., or leave the plug unplugged until November.

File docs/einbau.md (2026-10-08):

🇬🇧 [English version](einbau.en.md)

# Aufbau, Inbetriebnahme, Einbau und Test

Zurück zur [README](../README.md). Stand 08.10.2026. Einmessen siehe [einmessen.md](einmessen.md).

---

## Teil A: Knoten `ibc-wasser` (Container A)

### A1. Aufbau am Tisch

1. Gehäuse vorbereiten: M12-Verschraubungen einkleben (siehe README Abschnitt 5, Bestückung A).
2. Sensor anschließen: rot → 3V3, schwarz → G, weiß → D7, **gelb frei**.
   Zum Testen gehen Jumperkabel in den JST-PH-Stecker (2 mm Raster), draußen besser anlöten.
   Das Sensorkabel ist nur ~32 cm lang, deshalb sitzt der D1 mini direkt daneben im Kombi-Gehäuse. Das Kabel **nicht** verlängern. Bei UART 9600 ginge es zwar über mehrere Meter, ist aber unnötig.
3. Stromkabel: langes USB-Kabel durch eine Verschraubung, Adern an **5V** und **G** anlöten.
4. Funktionstest am Tisch: einschalten, in HA `IBC Wasser Abstand Wasser` beobachten, Sensor gegen die Zimmerdecke halten.
   Beim Test am 06.10. ergab das 1,37–1,47 m, und eine Hand darunter wurde sofort erkannt.
5. Sensor mit Silikonraupe ins Fenster setzen, Kabelschlitz der Trennwand abdichten, D1 mini fixieren.
   Den Deckel erst nach dem Aushärten aufsetzen (4 × 3 × 16).

### A2. Stelle auf dem IBC

Foto mit Markierung: [`fotos/ibc-sensorposition.jpg`](../fotos/ibc-sensorposition.jpg)

- auf der IBC-**Oberseite neben** der Einfüllöffnung, **nicht** im Schraubdeckel. Dort sitzen das HT-Rohr DN50 und das Pumpensteigrohr
- vorderes Feld zwischen den beiden Längsstreben des Stahlkäfigs, links neben der senkrechten Mulde („Rinne meiden“), vor der Pressschrift
- Abstand **≥ 30 cm zur Pumpe** (aus dem Foto ~35 cm geschätzt) und **≥ 20 cm zur Seitenwand**, wegen des 60°-Schallkegels
- die Stelle ist eben (Jens, 07.10.). Platzbedarf auf dem IBC ~111 × 99 mm. Ob das zwischen die Streben passt, hat Jens gemessen, ein Ergebnis ist **nicht notiert**

### A3. Montage

1. Mit dem Gehäuse als Schablone das **Fenster unten (68 × 33)** anzeichnen und einen Ausschnitt **70 × 35 mm** in die IBC-Oberseite schneiden.
   Späne aus dem Container fischen.
2. Die 4 Flanschlöcher anzeichnen, im IBC **3,2 mm vorbohren**.
3. **Dichtband** unter den Flansch. Randvoll steht Wasser am Flansch an, und PE lässt sich schlecht kleben.
4. Mit **4 Edelstahl-Blechschrauben 4,2 × 16** festschrauben. Muttern wären innen nicht erreichbar.
5. Optional die Kabel mit Kabelbindern an der Käfigstrebe sichern. USB-Netzteil an eine Steckdose unter Dach.
6. Einmessen → [einmessen.md](einmessen.md), Abschnitt 1. Dabei den Schwimmer-Block aus der Firmware A entfernen.

---

## Teil B: Knoten `ibc-b` (Container B)

### B1. Stand der Innenverdrahtung (08.10.)

Fertig und getestet: D0–RST-Brücke, A0-Teiler (100 k + 22 k = 121,5 kΩ gemessen), Schwimmer an D5/G. Schaltplan: [`plaene/ibc-b-schaltplan.pdf`](../plaene/ibc-b-schaltplan.pdf).

### B2. Akku und Shield

1. Akku nur einsetzen, wenn er den Selbstentladetest bestanden hat ([einmessen.md](einmessen.md), Abschnitt 4).
2. Polung: Der Aufdruck am Halter stimmt bei **beiden** Shields. Geprüft am 07.10.: „+“ piept gegen die Spule 3R3, „−“ nicht.
   Bei dieser Platinenserie ist ein Layoutfehler mit vertauschter Halterpolung bekannt, bei einem anderen Shield deshalb erneut messen.
3. Akku einlegen, dann am Shield **5V/GND** und **3V/GND** messen und notieren.
4. Shield **5V → D1 5V**, **GND → G**. **Kein USB am D1 mini gleichzeitig.**
5. ADC-Abgleich → [einmessen.md](einmessen.md), Abschnitt 2.

### B3. Solarpanel (nach der Lieferung ab 02.11.)

1. Vor dem Löten ein **Foto der Pads der fehlenden USB-Buchse U1** machen und klären, welches Pad VBUS ist.
2. **Z-Diode BZX 85C6V2 parallel** an den Eingang, **Ring (Kathode) an +**.
   Grund: Das Panel liefert im Leerlauf bis 8,2 V, der Shield-Eingang verträgt laut Händler nur 6,5 V. Das Panel ist strombegrenzt, die Z-Diode wird nur bei vollem Akku und Sonne warm.
3. Panelkabel H05RN-F 2 × 0,75 (~2–3 m) durch die zweite M12-Verschraubung. Das Panel hängt **außen am Schuppen**.

### B4. Gehäuse und Montage

1. Gehäuse B drucken (`ibc_b_gehaeuse.stl` + `ibc_b_deckel.stl`).
2. Shield und D1 einsetzen (Antennenende nach oben), Widerstände in die Klemmleiste.
3. Schwimmer- und Panelkabel unten durch die M12. Reicht ein Kabel nicht, **innen** an einer Klemme verlängern, nicht draußen.
4. Gehäuse **senkrecht hängend** an den Käfig von B, Verschraubungen **nach unten**, Deckel nach vorn. Befestigung per Kabelbinder durch die Laschenschlitze oder Schraube 4 mm.

### B5. Schwimmer einbauen

1. Schwimmer in den Halter: Gewinde durch das 19,5-mm-Loch (Platte 6 mm), Dichtring, Mutter. Das Gewinde ist 19,5 mm lang, es bleiben ~11 mm Rest.
   **Pfeil beachten** → Schaltrichtung „öffnet bei Wasser“ ([einmessen.md](einmessen.md), Abschnitt 3).
2. Kabel mit Kabelbindern durch die Schlitze am Steg.
3. Den Halter mit dem Haken über den Rand des Einfüllstutzens von B hängen (Stutzenwand 11,1 mm, innen 220,3 mm). Der Schwimmer zeigt waagrecht ins Innere.
   **B bleibt ohne Deckel**, denn der äußere Hakenschenkel sitzt über dem Gewinde.

### B6. WLAN am Standort

Ein Außen-AP ist ~10 m Luftlinie entfernt. Bei Problemen vorher testen: D1 per Powerbank an B, `IBC B WLAN-Signal` beobachten. Am PC waren es −57 dBm, in HA zuletzt −55 bis −63.
Eine externe Antenne (bzw. ein D1 mini Pro) wird erst gekauft, wenn das Ergebnis schlecht ist.

---

## Teil C: Pumpe und Home Assistant

1. Nous-Zigbee-Steckdose unter Dach bzw. in einer Schutzbox, denn sie ist ein Innengerät. Power-outage-memory muss **off** bleiben.
2. Pumpe einstecken, Normalleistung messen ([einmessen.md](einmessen.md), Abschnitt 5).
3. `ha/ibc-pumpe.yaml` anpassen (Leistungsschwelle) und einspielen (README Abschnitt 8).

---

## Teil D: Abnahmetest

| # | Test | Erwartung |
|---|---|---|
| 1 | Füllstand A plausibel (Zollstock-Gegenprobe) | Abweichung ≤ ~1 % |
| 2 | Knoten B meldet regelmäßig | `sensor.ibc_b_akku` alle ~15 min neu (`last_reported`) |
| 3 | Schwimmer B hochklappen (von Hand) | „Zielcontainer voll“ an → bei laufender Pumpe sofort aus + Push. B ist dabei wach, weil die Pumpe läuft. Schläft B, wird das erst beim nächsten Aufwachen erkannt |
| 4 | Schwimmerkabel abziehen | „voll“ = an, Pumpe gesperrt |
| 5 | Pumpe von Hand starten, Knoten B stromlos machen | nach > 180 s ohne Meldung: Pumpe aus + Push |
| 6 | Laufzeitgrenze (in HA testweise `for` verkürzen) | nach Ablauf aus + Sperre + Push; Sperre nur von Hand lösen |
| 7 | Knoten A stromlos | nach 15 min: Pumpe aus + Push |
| 8 | Regulärer Lauf A ≥ 90 % → ≤ 70 % | Start beim nächsten B-Aufwachen, Stopp bei 70 %, B schläft danach wieder |
| 9 | Akkuverlauf B über einige Tage | kein stetiger Abfall bei Sonne. Sonst ist der Ruhestrom zu hoch, etwa durch eine schlechte Shield-Charge |

Tests 3–7 **vor** der Abwesenheit ab 23.10. durchführen, oder die Steckdose bis November ausgesteckt lassen.

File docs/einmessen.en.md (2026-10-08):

🇩🇪 [Deutsche Version](einmessen.md)

# Calibration

Back to the [README](../README.en.md). As of 08.10.2026.

Four things are calibrated:

1. Node A: empty and full distance of the ultrasonic sensor, i.e. 0 % and 100 %
2. Node B: ADC factor of the battery voltage
3. Node B: switching direction of the float
4. Pump: normal power and, derived from it, the dry-run threshold in HA

In addition there is the self-discharge test of the battery before installation.

---

## 1. Node A: calibrating the fill level

**When:** only **after mounting** the combined enclosure on the IBC, because the measurement starts at the actual transducer surface.

### Basics

- The sensor measures the distance **transducer surface → water surface** in mm (`sensor.ibc_wasser_abstand_wasser`).
- The transducer surface lies ~1.5 mm **below** the IBC top surface. This is negligible for the calculation.
- The sensor is blind below ~30 mm (A02YYUW: minimum distance 3 cm). That is why "full" is not brim-full.
- Container A has **no overflow**. 100 % is therefore defined as **50 mm below the top surface**: decision of 07.10., set as an assumption, not derived from an overflow dimension.

### Formulas (as they are in the firmware)

```
Füllstand_% = (abstand_leer_mm − Abstand) / (abstand_leer_mm − abstand_voll_mm) × 100      → auf 0…100 begrenzt
Inhalt_L    = Füllstand_% / 100 × volumen_l                                                (volumen_l = 1000)
Liter pro cm = volumen_l / ((abstand_leer_mm − abstand_voll_mm) / 10)                       (≈ 10 l/cm)
```

(`Füllstand_%` = fill level %, `Abstand` = measured distance, `Inhalt_L` = content in litres, `Liter pro cm` = litres per cm; "auf 0…100 begrenzt" = clamped to 0…100.)

### Step by step

1. **Calm water:** pump off, no rain inflow. Wait about one minute, because the median filter needs 10 new values and values are sent at most every 30 s.
2. **Read the sensor value:** `IBC Wasser Abstand Wasser` (water distance) in HA, e.g. `d = 612 mm`. Wait for two or three values; they should differ by a few mm at most.
3. **Measure the water depth:** folding rule vertically through the filler opening down to the bottom, read the water line, e.g. `h = 395 mm`.
   - The pump stands in the middle of the bottom. Place the folding rule next to it, not on the pump.
4. **Calculate the empty value:**
   ```
   abstand_leer_mm = d + h          Beispiel: 612 + 395 = 1007
   ```
   (Beispiel = example)
5. **Set the full value:** `abstand_voll_mm = 50`.
6. **In the ESPHome Builder** open the YAML of `ibc-wasser` (the Builder is authoritative) and there:
   - enter `abstand_leer_mm` and `abstand_voll_mm`,
   - **delete the whole `binary_sensor` block "Zielcontainer voll" (target container full, GPIO14)**, because the float sits at node B. Otherwise A permanently reports "target full",
   - update the header comment ("mittig im Deckel" / centred in the cap, "Schwimmer … D5" / float … D5),
   - *Install → Wirelessly*.
7. **Check:** the fill level should now correspond to `h / (leer − 50) × 100` (leer = empty). In the example: 395 / 957 × 100 ≈ 41 %, i.e. ≈ 413 L.
8. In HA remove the orphaned entity `binary_sensor.ibc_wasser_zielcontainer_voll`.
9. Copy the new Builder YAML into the repo (`firmware/ibc-wasser.yaml`).

### Cross-check (recommended)

At a different water level, e.g. after the next rain or a pump run, repeat steps 2–3 and compute `d + h` again.
If it deviates by more than ~10 mm from the entered empty value, there are several possible causes. **None of them has been verified:**
- The IBC bottom is not flat. Many IBCs slope towards the outlet; then `h` depends on where you measure.
- Echoes from the riser pipe, corrugated hose or wall, because the sound cone is 60° wide.
- The folding rule was held at an angle.

### Notes

- The real volume of a "1000 l" IBC was **not** measured. If the litre value is wrong, adjust `volumen_l`. The % value is not affected.
- With an almost empty container, **wall echoes** are possible because of the 60° cone. Treat values below ~10 % with caution.
- The pump logic only uses % (thresholds 70/90/97 %). An error in the empty value shifts these thresholds.

---

## 2. Node B: calibrating the battery voltage (ADC factor)

**Background:** The D1 mini has an internal 220 kΩ / 100 kΩ divider on A0; the ADC full-scale value is 1.0 V. In front of it are 100 kΩ + 22 kΩ in series, measured together **121.5 kΩ**.

```
adc_faktor (theoretisch) = (R_vor + 220k + 100k) / 100k
                         = (122 + 220 + 100) / 100 = 4,42          (in der Firmware)
                         = (121,5 + 220 + 100) / 100 = 4,415       (mit gemessenem R_vor)
Messbereich ≈ 4,42 V
```

(theoretisch = theoretical, `R_vor` = series resistor, "in der Firmware" = as in the firmware, "mit gemessenem R_vor" = with the measured series resistor, Messbereich = measuring range.)

The internal resistors of the D1 mini have tolerances. That is why the value is calibrated against a multimeter.

### Step by step

1. Prerequisites: the battery has passed the self-discharge test (section 4), shield 5V/GND is connected to the D1 mini, **no USB on the D1 mini**.
2. In HA switch **on** `IBC B wach halten` (keep awake) and wait for the next wake-up. After plugging in or a reset it is awake for 10 min anyway.
3. Use the multimeter to measure the voltage **at the holder contact battery+ against GND**: `U_mm`.
4. At the same time read `sensor.ibc_b_akku` in HA: `U_ha`. While awake it is updated every 60 s.
5. New factor:
   ```
   adc_faktor_neu = adc_faktor_alt × U_mm / U_ha
   Beispiel: 4,42 × 3,95 / 4,01 = 4,354
   ```
   (neu = new, alt = old, Beispiel = example)
6. In the Builder change `adc_faktor` in `ibc-b` → OTA (while "keep awake" is on).
7. Check after the restart, then switch "keep awake" **off**.

### Battery charge (%)

The firmware calculates roughly linearly: `% = (U − 3,3) / (4,15 − 3,3) × 100`, clamped to 0…100. This is only a rough guide, because the Li-ion discharge curve is not linear.

### Thresholds

| Voltage | Effect |
|---|---|
| < 3.4 V | push "Akku schwach" (battery low) (HA) |
| < 3.3 V | node sleeps 2 h instead of 15 min (firmware) |
| 2.4 V | over-discharge protection of the shield (DW01, according to research) |
| 4.20 V | end-of-charge voltage TC4056 |

---

## 3. Node B: float switching direction

Goal: **"opens with water"**. An open contact then means full **or** cable break, and both lock the pump.

1. There is an arrow on the float body; it indicates the mounting orientation. Rotated by 180°, the switching direction is reversed.
2. Check on the bench before installation: keep node B awake, connect the float.
   - Hinged float **hanging down** (no water) → contact must be **closed** → `IBC B Zielcontainer voll` (target container full) = **off**.
   - Hinged float **flipped up** (water) → contact **open** → **on** after 2 s.
3. If it is wrong, rotate the float in the holder by 180°. Do **not** invert the firmware, because then a cable break would be read as "empty".

Bench test of 08.10. (wire jumper instead of float): short circuit → off (17:32:35), open → on (17:32:40). Passed.

**Switching point:** the holder places the threaded hole 120 mm below the rim of the neck. The float switches at roughly the height of the hole *(approximate, not measured)*.

---

## 4. Battery self-discharge test (before installation)

Applies to the e-cigarette battery. It was deeply discharged (2.78 V), was charged under supervision in the left-hand shield via micro-USB and has been resting outside the shield since then.

| Point in time | Voltage |
|---|---|
| 07.10. ~21:05 (start of charging) | 2.78 V |
| 08.10. 14:25 (reference value, loose outside the shield) | **4.137 V** |
| 09.10. ~14:30 (evaluation) | ≥ 4.09 V good · 4.04–4.09 V borderline · < 4.04 V discard |

Check beforehand: wrap undamaged, note marking/type. **Do not charge Li-ion below 0 °C.** For winter operation outdoors this has not been solved yet *(open)*.

If the battery fails, the EVE 18650-33V from the reichelt order on 02.11. will be used.

---

## 5. Pump: normal power and dry-run threshold

1. Plug in the plug. During the **first real run** (A well filled, hose to B open) read the power `sensor.steckdose_ibc_wassercontainer_pumpe_power` after ~1 min: `P_normal`.
2. Calculate the threshold: `P_schwelle ≈ 0,6 × P_normal` (Schwelle = threshold), e.g. 350 W → 210 W.
3. In `ha/ibc-pumpe.yaml`, automation `ibc_pumpe_sicherung`, replace `below: 20` with `P_schwelle`.
4. **Check the flow rate:** the rule "dropped less than 2 % after 10 min → lock" requires at least ~2 l/min, because 2 % ≈ 20 l.
   Read the fill level of A after 10 min of run time. If the pump delivers close to this limit, adjust the threshold or the time.
5. Check whether A gets from 90 % to 70 % within 30 min (run-time limit), i.e. ~200 l. Otherwise the 30 min lock will trigger every time.

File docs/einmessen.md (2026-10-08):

🇬🇧 [English version](einmessen.en.md)

# Einmessen und Kalibrieren

Zurück zur [README](../README.md). Stand 08.10.2026.

Eingemessen werden vier Dinge:

1. Knoten A: Leer- und Vollabstand des Ultraschallsensors, also 0 % und 100 %
2. Knoten B: ADC-Faktor der Akkuspannung
3. Knoten B: Schaltrichtung des Schwimmers
4. Pumpe: Normalleistung und daraus die Trockenlauf-Schwelle in HA

Dazu kommt der Selbstentladetest des Akkus vor dem Einbau.

---

## 1. Knoten A: Füllstand einmessen

**Wann:** erst **nach der Montage** des Kombi-Gehäuses auf dem IBC, denn gemessen wird ab der tatsächlichen Wandlerfläche.

### Grundlagen

- Der Sensor misst den Abstand **Wandlerfläche → Wasseroberfläche** in mm (`sensor.ibc_wasser_abstand_wasser`).
- Die Wandlerfläche liegt ~1,5 mm **unter** der IBC-Oberseite. Das ist für die Rechnung vernachlässigbar.
- Der Sensor ist unterhalb von ~30 mm blind (A02YYUW: Mindestabstand 3 cm). Deshalb ist „voll“ nicht randvoll.
- Container A hat **keinen Überlauf**. Als 100 % gilt deshalb **50 mm unter der Oberseite**: Entscheidung vom 07.10., als Annahme festgelegt, nicht aus einem Überlaufmaß abgeleitet.

### Formeln (so stehen sie in der Firmware)

```
Füllstand_% = (abstand_leer_mm − Abstand) / (abstand_leer_mm − abstand_voll_mm) × 100      → auf 0…100 begrenzt
Inhalt_L    = Füllstand_% / 100 × volumen_l                                                (volumen_l = 1000)
Liter pro cm = volumen_l / ((abstand_leer_mm − abstand_voll_mm) / 10)                       (≈ 10 l/cm)
```

### Schritt für Schritt

1. **Ruhiges Wasser:** Pumpe aus, kein Regen-Zulauf. Etwa eine Minute warten, denn der Medianfilter braucht 10 neue Werte, und gesendet wird höchstens alle 30 s.
2. **Sensorwert ablesen:** `IBC Wasser Abstand Wasser` in HA, z. B. `d = 612 mm`. Zwei, drei Werte abwarten, sie sollten sich höchstens um wenige mm unterscheiden.
3. **Wassertiefe messen:** Zollstock an der Einfüllöffnung senkrecht bis auf den Boden, Wasserlinie ablesen, z. B. `h = 395 mm`.
   - Die Pumpe steht mittig am Boden. Den Zollstock daneben ansetzen, nicht auf der Pumpe.
4. **Leerwert rechnen:**
   ```
   abstand_leer_mm = d + h          Beispiel: 612 + 395 = 1007
   ```
5. **Vollwert setzen:** `abstand_voll_mm = 50`.
6. **Im ESPHome Builder** die YAML von `ibc-wasser` öffnen (der Builder ist führend) und dort:
   - `abstand_leer_mm` und `abstand_voll_mm` eintragen,
   - **den ganzen `binary_sensor`-Block „Zielcontainer voll“ (GPIO14) löschen**, denn der Schwimmer sitzt an Knoten B. Sonst meldet A dauerhaft „Ziel voll“,
   - den Kopfkommentar („mittig im Deckel“, „Schwimmer … D5“) aktualisieren,
   - *Install → Wirelessly*.
7. **Kontrolle:** Der Füllstand sollte jetzt `h / (leer − 50) × 100` entsprechen. Im Beispiel: 395 / 957 × 100 ≈ 41 %, also ≈ 413 L.
8. In HA die verwaiste Entität `binary_sensor.ibc_wasser_zielcontainer_voll` entfernen.
9. Die neue Builder-YAML ins Repo übernehmen (`firmware/ibc-wasser.yaml`).

### Gegenprobe (empfohlen)

Bei einem anderen Wasserstand, etwa nach dem nächsten Regen oder einem Pumpenlauf, Schritte 2–3 wiederholen und `d + h` erneut bilden.
Weicht das um mehr als ~10 mm vom eingetragenen Leerwert ab, gibt es mehrere mögliche Ursachen. **Keine davon ist geprüft:**
- Der IBC-Boden ist nicht eben. Viele IBC haben ein Gefälle zum Auslass, dann hängt `h` vom Messort ab.
- Echos von Steigrohr, Wellschlauch oder Wand, weil der Schallkegel 60° breit ist.
- Der Zollstock wurde schräg gehalten.

### Hinweise

- Das reale Volumen eines „1000-l“-IBC wurde **nicht** nachgemessen. Stimmt der Literwert nicht, `volumen_l` anpassen. Der %-Wert bleibt davon unberührt.
- Bei fast leerem Container sind wegen des 60°-Kegels **Wandechos** möglich. Werte unter ~10 % mit Vorsicht lesen.
- Die Pumpenlogik nutzt nur % (Schwellen 70/90/97 %). Ein Fehler im Leerwert verschiebt diese Schwellen.

---

## 2. Knoten B: Akkuspannung abgleichen (ADC-Faktor)

**Hintergrund:** Der D1 mini hat an A0 intern einen Teiler 220 kΩ / 100 kΩ, der ADC-Endwert liegt bei 1,0 V. Davor sitzen 100 kΩ + 22 kΩ in Reihe, gemessen zusammen **121,5 kΩ**.

```
adc_faktor (theoretisch) = (R_vor + 220k + 100k) / 100k
                         = (122 + 220 + 100) / 100 = 4,42          (in der Firmware)
                         = (121,5 + 220 + 100) / 100 = 4,415       (mit gemessenem R_vor)
Messbereich ≈ 4,42 V
```

Die internen Widerstände des D1 mini haben Toleranzen. Deshalb wird gegen ein Multimeter abgeglichen.

### Schritt für Schritt

1. Voraussetzungen: Der Akku hat den Selbstentladetest bestanden (Abschnitt 4), Shield-5V/GND hängt am D1 mini, **kein USB am D1 mini**.
2. In HA `IBC B wach halten` **ein**schalten und auf das nächste Aufwachen warten. Nach Einstecken oder Reset ist er ohnehin 10 min wach.
3. Mit dem Multimeter die Spannung **am Halterkontakt Akku+ gegen GND** messen: `U_mm`.
4. Gleichzeitig in HA `sensor.ibc_b_akku` ablesen: `U_ha`. Er wird im Wachzustand alle 60 s aktualisiert.
5. Neuer Faktor:
   ```
   adc_faktor_neu = adc_faktor_alt × U_mm / U_ha
   Beispiel: 4,42 × 3,95 / 4,01 = 4,354
   ```
6. Im Builder `adc_faktor` in `ibc-b` ändern → OTA (solange „wach halten“ an ist).
7. Kontrolle nach dem Neustart, dann „wach halten“ **aus**schalten.

### Akku-Ladung (%)

Die Firmware rechnet grob linear: `% = (U − 3,3) / (4,15 − 3,3) × 100`, begrenzt auf 0…100. Das ist nur ein Richtwert, denn die Li-Ion-Kennlinie ist nicht linear.

### Schwellen

| Spannung | Wirkung |
|---|---|
| < 3,4 V | Push „Akku schwach“ (HA) |
| < 3,3 V | Knoten schläft 2 h statt 15 min (Firmware) |
| 2,4 V | Tiefentladeschutz des Shields (DW01, laut Recherche) |
| 4,20 V | Ladeschluss TC4056 |

---

## 3. Knoten B: Schwimmer-Schaltrichtung

Ziel: **„öffnet bei Wasser“**. Ein offener Kontakt bedeutet dann voll **oder** Kabelbruch, und beides sperrt die Pumpe.

1. Am Schwimmerkörper ist ein Pfeil, er zeigt die Einbaulage. Um 180° gedreht kehrt sich die Schaltrichtung um.
2. Vor dem Einbau am Tisch prüfen: Knoten B wach halten, Schwimmer anschließen.
   - Klappschwimmer **hängt** (kein Wasser) → Kontakt muss **geschlossen** sein → `IBC B Zielcontainer voll` = **aus**.
   - Klappschwimmer **hochgeklappt** (Wasser) → Kontakt **offen** → nach 2 s **an**.
3. Stimmt es nicht, Schwimmer im Halter um 180° drehen. **Nicht** die Firmware invertieren, denn dann würde ein Kabelbruch als „leer“ gelesen.

Tischtest vom 08.10. (Drahtbrücke statt Schwimmer): Kurzschluss → aus (17:32:35), offen → an (17:32:40). Bestanden.

**Schaltpunkt:** Der Halter setzt das Gewindeloch 120 mm unter den Stutzenrand. Der Schwimmer schaltet etwa auf Lochhöhe *(ungefähr, nicht ausgemessen)*.

---

## 4. Akku-Selbstentladetest (vor dem Einbau)

Gilt für den E-Zigarettenakku. Er war tief entladen (2,78 V), wurde im linken Shield per Micro-USB beaufsichtigt geladen und ruht seitdem außerhalb des Shields.

| Zeitpunkt | Spannung |
|---|---|
| 07.10. ~21:05 (Ladebeginn) | 2,78 V |
| 08.10. 14:25 (Bezugswert, lose außerhalb des Shields) | **4,137 V** |
| 09.10. ~14:30 (Bewertung) | ≥ 4,09 V gut · 4,04–4,09 V grenzwertig · < 4,04 V aussortieren |

Vorher prüfen: Folie unbeschädigt, Aufdruck/Typ notieren. Li-Ion **nicht unter 0 °C laden**. Für den Winterbetrieb draußen ist das bislang nicht gelöst *(offen)*.

Fällt der Akku durch, kommt der EVE 18650-33V aus der reichelt-Bestellung am 02.11.

---

## 5. Pumpe: Normalleistung und Trockenlauf-Schwelle

1. Steckdose einstecken. Beim **ersten echten Lauf** (A gut gefüllt, Schlauch zu B offen) die Leistung `sensor.steckdose_ibc_wassercontainer_pumpe_power` nach ~1 min ablesen: `P_normal`.
2. Schwelle rechnen: `P_schwelle ≈ 0,6 × P_normal`, z. B. 350 W → 210 W.
3. In `ha/ibc-pumpe.yaml`, Automation `ibc_pumpe_sicherung`, `below: 20` durch `P_schwelle` ersetzen.
4. **Fördermenge prüfen:** Die Regel „nach 10 min weniger als 2 % gesunken → Sperre“ setzt mindestens ~2 l/min voraus, denn 2 % ≈ 20 l.
   Den Füllstand von A nach 10 min Laufzeit ablesen. Fördert die Pumpe nahe dieser Grenze, Schwelle oder Zeit anpassen.
5. Prüfen, ob A in 30 min (Laufzeitgrenze) von 90 % auf 70 % kommt, also ~200 l. Sonst greift jedes Mal die 30-min-Sperre.

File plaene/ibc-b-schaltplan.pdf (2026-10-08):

# IBC Container B Solar-Knoten Schaltplan

Wemos D1 mini (ESP8266) · 18650 Battery Shield V3 (rechtes, ohne USB-Buchse) · Schwimmer Ziel voll · Stand 07.10.2026

## Solarpanel 1 W

## 18650 Battery Shield V3

## Wemos D1 mini

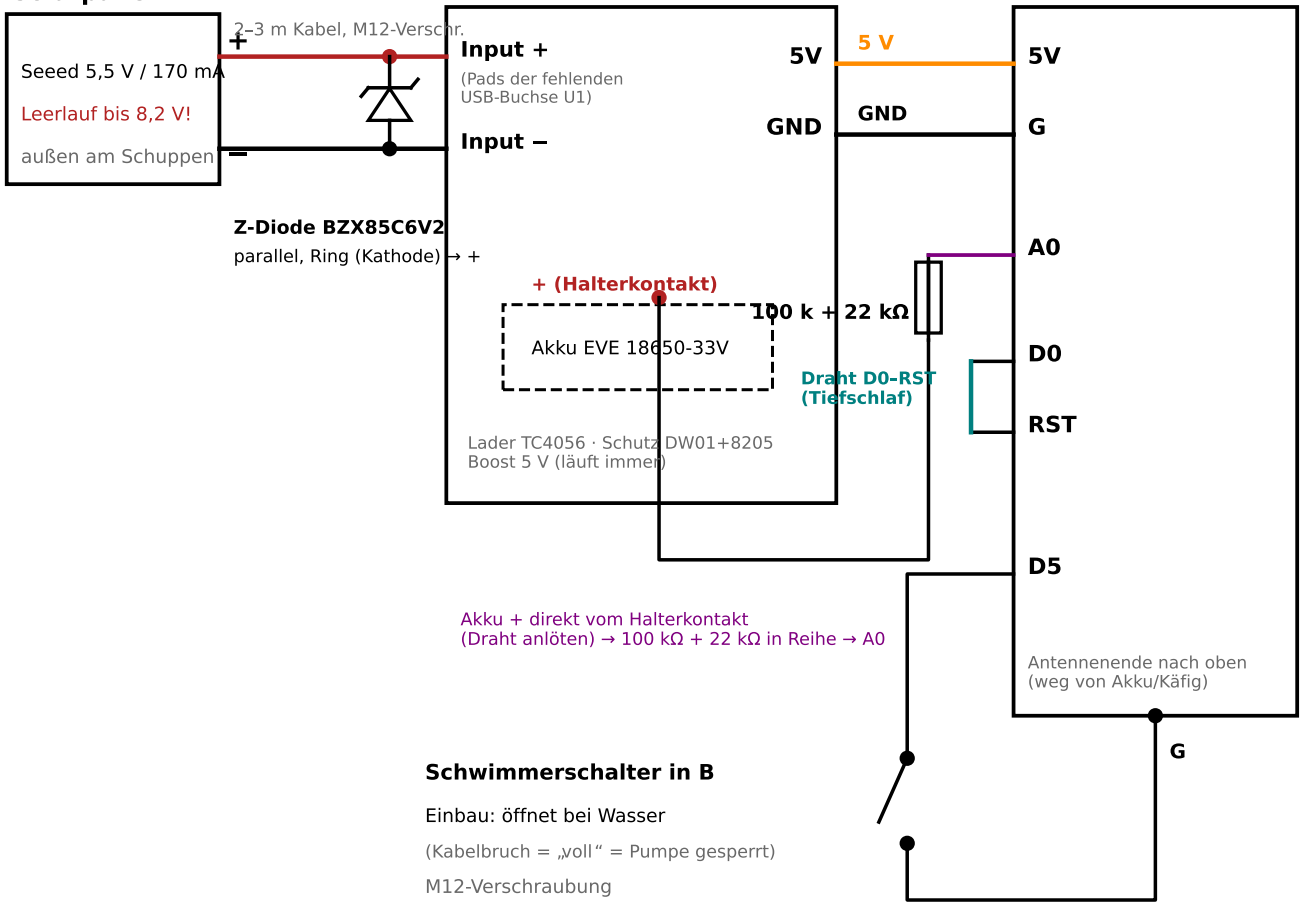
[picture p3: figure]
Seeed 5,5 V / 170 mA; Leerlauf bis 8,2 V!; außen am Schuppen; 2 3 m Kabel, M12-Verschr.; Z-Diode BZX85C6V2; parallel, Ring (Kathode); Input +; Input; (Pads der fehlenden USB-Buchse U1); Akku EVE 18650-33V; + (Halterkontakt); Lader TC4056 · Schutz; Boost 5 V (läuft immer); GND; RST; Antennenende nach oben (weg von Akku/Käfig); Akku + direkt vom Halterkontakt; Draht D0 RST (Tiefschlaf); Schwimmerschalter in B; Einbau: öffnet bei Wasser; (Kabelbruch = voll = Pumpe gesperrt); M12-Verschraubung

(Draht anlöten) | 100 k + 22 k in Reihe | A0

# Hinweise

Z-Diode PARALLEL an den Eingang, Ring (Kathode) an +. Ohne sie liegt bei vollem Akku die Leerlaufspannung des Panels

(bis 8,2 V) am Eingang das Shield verträgt laut Händler nur 6,5 V.

Panel an die Pads der fehlenden USB-Buchse U1 (VBUS = +, GND = ). Vor dem Löten Foto der Pads an Claude: welches Pad ist VBUS.

Akku erst einlegen, wenn alles verdrahtet ist; Polung am Halter ist geprüft (Aufdruck stimmt, 07.10.).

D1 mini über den 5-V-Pin versorgen (Boost des Shields). Der 3-V-Ausgang des Shields ist ohne Kondensator instabil NICHT nehmen.

A0: Der D1 mini hat intern 220 k /100 k (3,2 V Endwert); mit 100 k + 22 k in Reihe davor (= 122 k ) misst er bis ~4,4 V. Dauerstrom ~10 µA.

D0 RST-Draht ist für den Tiefschlaf nötig. Klappt das Flashen per USB nicht, den Draht kurz abziehen.

Schwimmer an D5 (GPIO14) und G, interner Pull-up. Geschlossen = Wasser unten, offen = B voll ODER Kabel ab | Pumpe gesperrt.
Verbrauch (geschätzt): Shield ~0,3 mA + D1 im Schlaf ~0,2 mA + 96× Aufwachen | 25 mAh/Tag | EVE 3200 mAh | 4 Monate ohne Sonne.

Zum Aktualisieren (OTA) in HA IBC B wach halten einschalten und auf das nächste Aufwachen warten (max. 15 min).

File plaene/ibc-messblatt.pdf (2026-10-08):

## IBC-Wasserstand – Messblatt

Stand 06.10.2026 · Messschieber + Zollstock · Werte in mm · Bei Unklarheit lieber Foto mit Zollstock daneben.

### A) Container A – Ultraschallsensor im Schraubdeckel

# | Was messen | Wie / Hinweis | Messwert

1 | Sensorkopf-Durchmesser | Messschieber, dickste Stelle des runden Kopfs (ohne Kabel). Angenommen: 24,5 | ________ mm
2 | Wandstärke Schraubdeckel | Deckel abschrauben, Messschieber an der flachen Mitte, wo das Loch hin soll. Angenommen: 4 | ________ mm
3 | Deckel: flache Fläche innen (Ø) | Durchmesser der ebenen Fläche oben auf dem Deckel (ohne Griffrippen) – passt der Halterflansch Ø 60? | ________ mm
4 | Abstand Deckeloberkante → Boden innen | Zollstock durch die Öffnung senkrecht bis auf den Boden; an der Deckel-Auflage ablesen. Wird „leer“-Wert. | ________ mm
5 | Abstand Deckeloberkante → höchster Wasserstand | Bis wohin darf A maximal voll werden (Überlaufkante/Oberkante Behälter innen)? Wird „voll“-Wert. | ________ mm
6 | Abstand Deckeloberkante → Wasser jetzt | Zum Gegenprüfen der ersten Messung. Uhrzeit notieren. | ________ mm um ____:____

### B) Zielcontainer (B oder C) – Schwimmerschalter

# | Was messen | Wie / Hinweis | Messwert

7 | Gewinde-Ø Schwimmerschalter | Messschieber außen über das Gewinde. Angenommen: 16,5 | ________ mm
8 | Länge Schwimmer ab Gewinde | Wie weit steht der Schwimmer-Arm vom Gewinde ab (nach innen)? | ________ mm
9 | Wandstärke Einfüllstutzen | Am Rand der Öffnung (Deckel ab), dort hängt der Halter ein. Angenommen: 6 | ________ mm
10 | Innen-Ø Einfüllstutzen | Passt Halter (22 mm breit) + Schwimmer durch? | ________ mm
11 | Schalthöhe unter Stutzenrand | Ab welcher Tiefe unter dem Rand soll „Ziel voll“ melden? (Wasser bis dahin = Pumpe stoppt). Angenommen: 120 | ________ mm
12 | Welcher Container wird zuerst voll? | Dort kommt der Schwimmer hin (B und C sind noch nicht verbunden). | B ☐ C ☐

### C) Kabel und Montage

# | Was messen | Wie / Hinweis | Messwert

13 | Kabellänge Sensor | Reicht das Sensorkabel vom Deckel A bis zum Platz der D1-Box? | ________ cm reicht ☐
14 | Abstand Deckel A → Schwimmer (B/C) | Kabelweg für den Schwimmerschalter zur D1-Box | ________ cm
15 | Steckdose / USB-Netzteil | Wo bekommt der D1 mini Strom? Abstand zur Box. | ________ cm
16 | Zigbee-Steckdose der Pumpe | Welche Steckdose (Name in HA / Aufkleber)? Draußen geeignet (IP44)? | ________________

Fett = für den Druck der Halter nötig. 4 + 5 = Einmessen (Füllstand 0 % / 100 %). Danach: Werte an Claude, STL wird angepasst, dann PETG drucken.

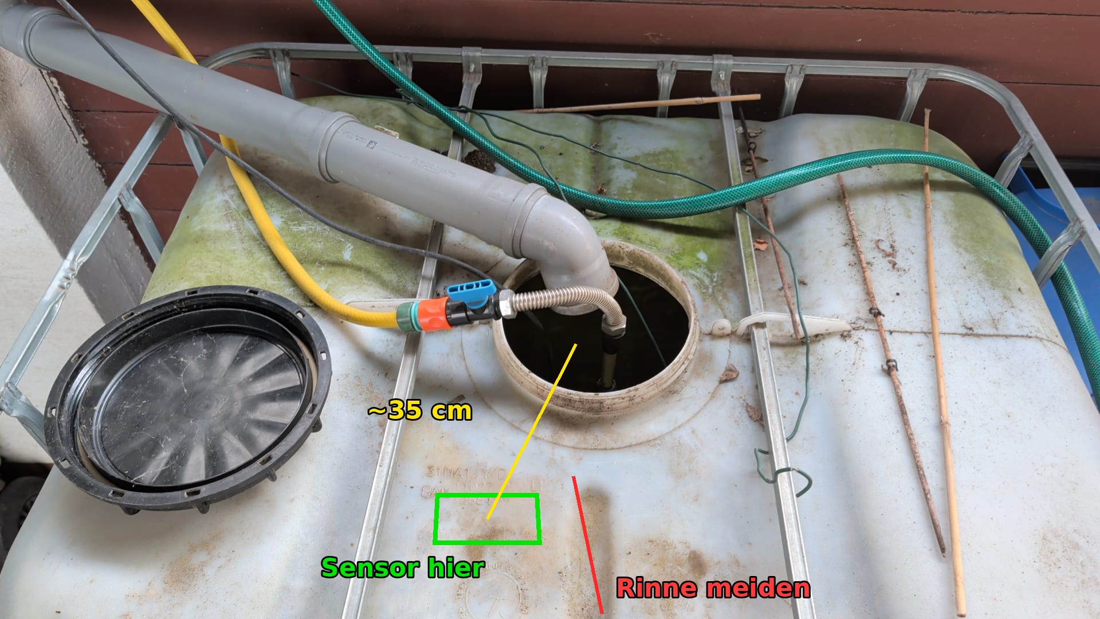
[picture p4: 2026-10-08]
fotos/ibc-sensorposition.jpg

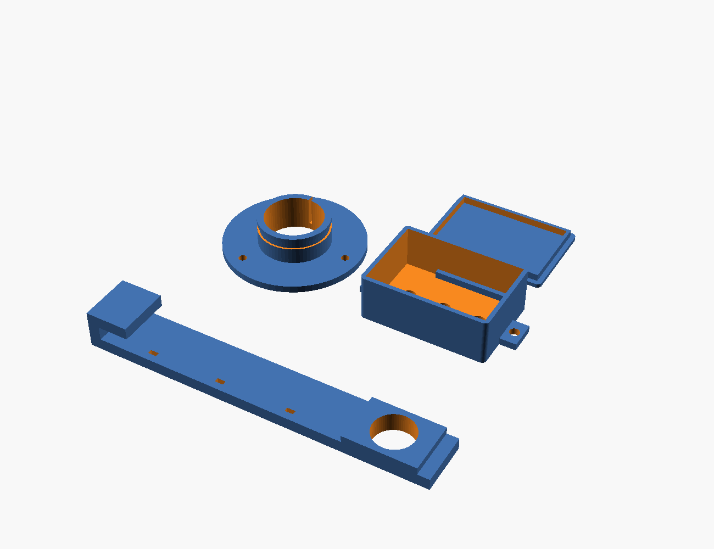
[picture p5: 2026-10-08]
gehaeuse/vorschau_ibc.png

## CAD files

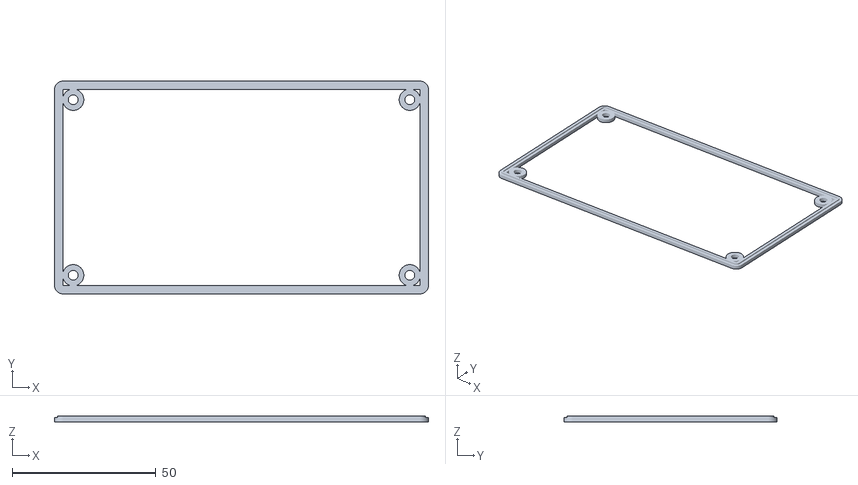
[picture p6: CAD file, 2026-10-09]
gehaeuse/ibc_b_dichtung.stl
130.0 x 74.0 x 2.19

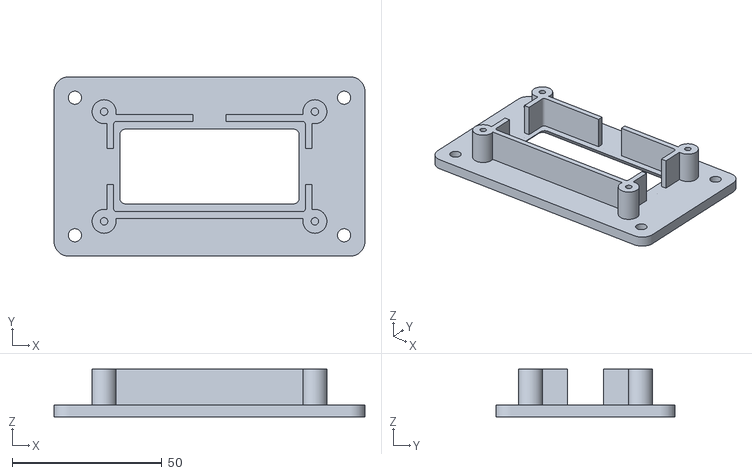
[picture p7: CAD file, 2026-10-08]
gehaeuse/ibc_sensor_halter.stl
104.0 x 60.0 x 16.0

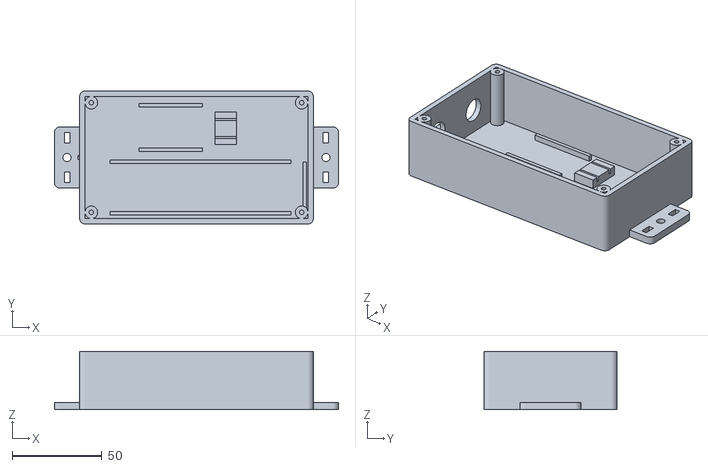
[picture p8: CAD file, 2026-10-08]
gehaeuse/ibc_b_gehaeuse.stl
158.0 x 74.0 x 32.4

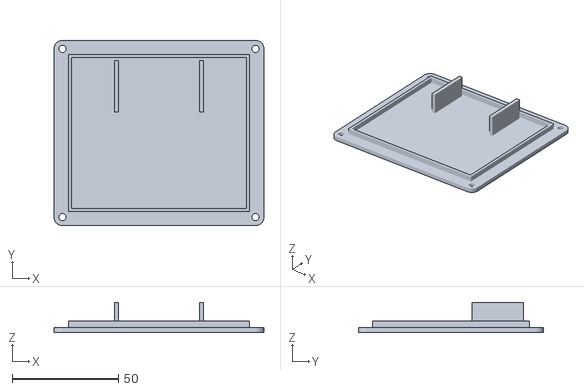
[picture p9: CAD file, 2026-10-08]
gehaeuse/ibc_kombi_deckel.stl
98.9 x 87.3 x 14.2

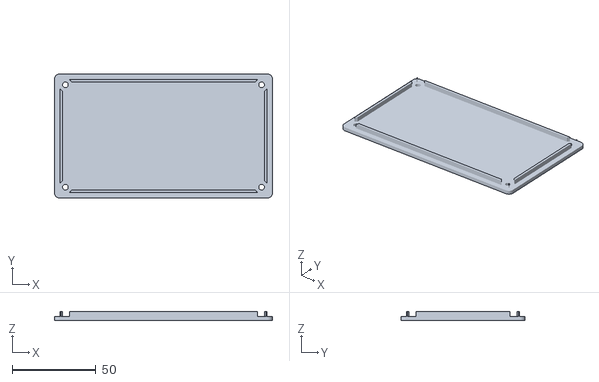
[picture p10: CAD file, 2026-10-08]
gehaeuse/ibc_b_deckel.stl
130.0 x 74.0 x 5.40

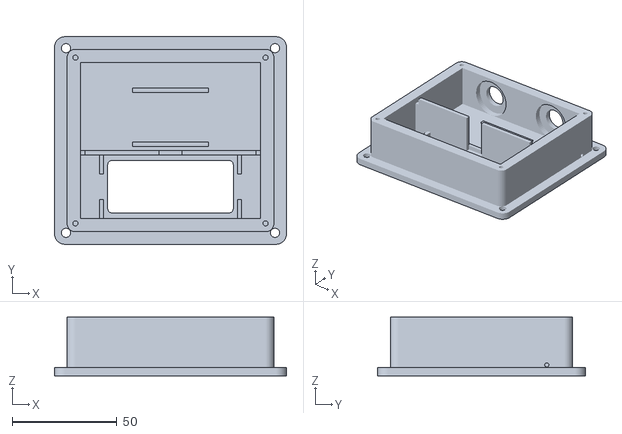
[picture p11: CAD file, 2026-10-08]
gehaeuse/ibc_kombi_gehaeuse.stl
110.9 x 99.3 x 28.0

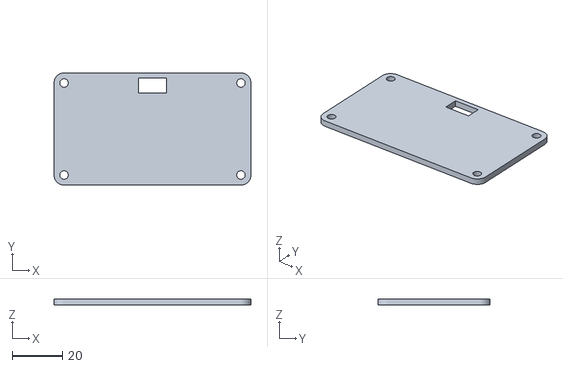
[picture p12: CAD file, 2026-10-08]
gehaeuse/ibc_sensor_abdeckung.stl
78.5 x 44.7 x 2.40

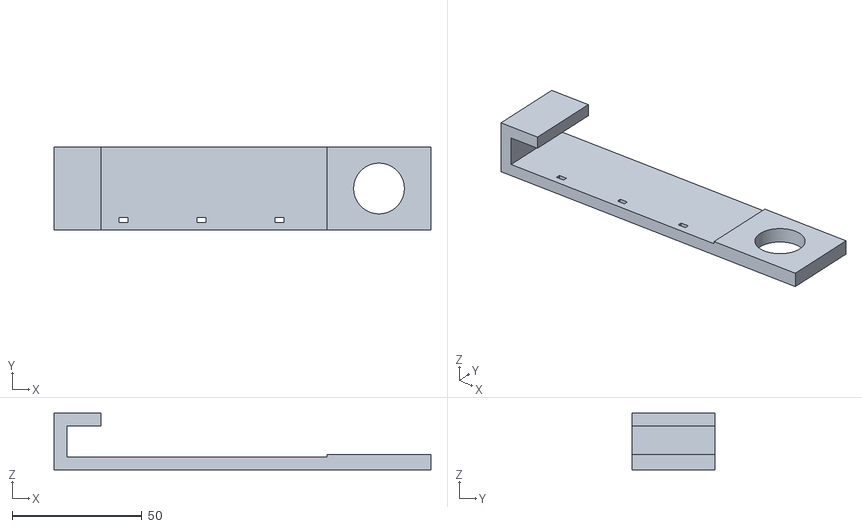
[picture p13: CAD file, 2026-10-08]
gehaeuse/ibc_schwimmer_halter.stl
145.0 x 32.0 x 21.9

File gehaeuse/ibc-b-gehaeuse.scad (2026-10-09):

// IBC Container B: Solar-Knoten — Gehaeuse fuer 18650 Battery Shield V3 (rechtes, ohne USB-Buchse) + Wemos D1 mini
// Stand 07.10.2026 — Notiz project_ibc_wasserstand.  PETG, ueberdacht/aussen am Kaefig von B.
//
// Lage beim Einbau: Gehaeuse HAENGT senkrecht am Kaefig, die Stirnwand mit den Verschraubungen zeigt NACH UNTEN
// (Tropfwasser laeuft ab), Deckel zeigt nach vorn.  Gedruckt wird liegend (Boden auf dem Bett).
//
// TEIL = "gehaeuse" | "deckel" | "alle"
//
// Shield-Masse gemessen 07.10.2026 (vorher geschaetzt):
//   ★ sh_l, sh_b  Shield-Platine (ohne USB-A-Buchse), ★ sh_usb Ueberstand der USB-A-Buchse
//   ★ sh_h        Hoehe Shield + eingelegter Akku (Unterseite Bauteile bis Oberkante Akku)

TEIL = "alle";
$fn = 64;

// ---------- Inhalt ----------
sh_l = 99.28; sh_b = 29.46; sh_usb = 6.74; sh_h = 25;   // gemessen 07.10. (Jens)
d1_l = 34.2; d1_b = 25.6;                             // Wemos D1 mini (bekannt)
spiel = 0.6;

// ---------- Gehaeuse ----------
w      = 3;      // Wand = 3 mm → Standard-M12-Verschraubung (Gewinde ~8 mm) samt Mutter fasst
boden  = 2.4;
il = 124;        // innen Laenge: Mutterzone 12 + Shield 98 + USB 6 + Eckdome
ib = 68;         // innen Breite: Shield 30 | Luft | D1 mini 26,6
ih = 30;         // innen Hoehe (★ sh_h + Leisten 3 + Luft)
al = il + 2*w; ab = ib + 2*w; ah = boden + ih;
dom_d = 7;  dom_loch = 2.5;   // Blechschraube 3 x 12 fuer den Deckel
m12 = 12.3;  m12_z = boden + 13;  m12_y = 15;   // zwei Verschraubungen: Schwimmer | Panel
lasche_l = 14;

function dome() = [for (sx=[-1,1], sy=[-1,1]) [sx*(il/2 - dom_d/2), sy*(ib/2 - dom_d/2)]];

module rbox(l, b, h, r=3) { hull() for (x=[-l/2+r, l/2-r], y=[-b/2+r, b/2-r]) translate([x,y,0]) cylinder(r=r, h=h); }

module gehaeuse() {
    difference() {
        union() {
            rbox(al, ab, ah, 3);
            // Befestigungslaschen oben und unten (Kabelbinder um die Kaefigstrebe oder Schraube 4 mm)
            for (sx=[-1,1]) translate([sx*(al/2 + lasche_l/2 - 2), 0, 0]) rbox(lasche_l + 4, 34, 4, 3);
        }
        translate([-il/2, -ib/2, boden]) cube([il, ib, ih + 1]);
        // M12 in der unteren Stirnwand (x = -), Wand 3 mm
        for (y=[-m12_y, m12_y]) translate([-al/2 - 1, y, m12_z]) rotate([0,90,0]) cylinder(d=m12, h=w + 2);
        // Kondenswasser-Ablauf ganz unten in der Stirnwand
        translate([-al/2 - 1, 0, boden + 1.2]) rotate([0,90,0]) cylinder(d=2.5, h=w + 2);
        // Laschen: Loch 4,5 + Schlitz fuer Kabelbinder (bis 5 mm breit)
        for (sx=[-1,1]) {
            translate([sx*(al/2 + lasche_l/2), 0, -1]) cylinder(d=4.5, h=6);
            for (y=[-11, 11]) translate([sx*(al/2 + lasche_l/2) - 1.5, y - 3, -1]) cube([3, 6, 6]);
        }
    }
    // Eckdome fuer die Deckelschrauben
    for (p=dome()) translate([p[0], p[1], boden]) difference() {
        cylinder(d=dom_d, h=ih);
        translate([0,0,ih - 12]) cylinder(d=dom_loch, h=13);
    }
    // Shield: zwei Laengsleisten (Bauteile auf der Unterseite bleiben frei); Fixierung mit Klebepad/Heisskleber
    sh_x0 = -il/2 + 14;                       // 14 mm Mutterzone vor den Verschraubungen frei
    sh_y0 = -ib/2 + 2;
    for (y=[sh_y0, sh_y0 + sh_b + 2*spiel - 2]) translate([sh_x0, y, boden]) cube([sh_l + 2*spiel, 2, 3]);
    // Anschlag am oberen Ende (USB-A-Seite)
    translate([sh_x0 + sh_l + sh_usb + 2*spiel, sh_y0, boden]) cube([2, sh_b, 6]);
    // D1 mini: Auflageleisten, Antenne (Ende ohne USB) zeigt nach OBEN, weg vom Akku und vom Kaefig
    d1_x0 = -il/2 + 30;  d1_y0 = ib/2 - 4 - d1_b - 2*spiel;
    for (y=[d1_y0, d1_y0 + d1_b + 2*spiel - 2]) translate([d1_x0, y, boden]) cube([d1_l + 2*spiel, 2, 3]);
    // Haltepunkt fuer 2 Widerstaende (Akku-Messung) als kleine Klemmleiste
    translate([d1_x0 + d1_l + 8, d1_y0 + 4, boden]) difference() { cube([12, 18, 5]); for (y=[4, 14]) translate([-1, y - 0.6, 2.5]) cube([14, 1.2, 3]); }
}

module deckel() {
    t = 2.4; lip_h = 3; lip_w = 1.4; sp = 0.35;
    difference() {
        rbox(al, ab, t, 3);
        for (p=dome()) translate([p[0], p[1], -1]) cylinder(d=3.4, h=t + 2);
    }
    // umlaufende Lippe nach innen, an den Eckdomen ausgespart
    translate([0,0,-lip_h]) difference() {
        rbox(il - 2*sp, ib - 2*sp, lip_h, 1);
        rbox(il - 2*sp - 2*lip_w, ib - 2*sp - 2*lip_w, lip_h + 1, 0.5);
        for (p=dome()) translate([p[0], p[1], -1]) cylinder(d=dom_d + 1, h=lip_h + 2);
    }
}

// TPU-Dichtung (09.10.2026, Jens): Rahmen auf der 3-mm-Wandoberkante + Ohren ueber den Eckdomen (Schraubenloch),
// innen frei fuer die Deckellippe (0,35 mm Luft), Ohren passen in die Lippen-Aussparung (Ø dom_d+1). Wulst oben
// auf Wandmitte wird beim Anziehen gequetscht. Druck: TPU 95A, liegend, 100 % Fuellung, langsam (~20 mm/s).
// Schraube: Deckel 2,4 + Dichtung 1,6 (+Wulst) → 3x12 greift noch ~7,5 mm im Dom.
dicht_t = 1.6;  wulst_b = 0.8;  wulst_h = 0.6;  ohr_d = dom_d + 0.4;   // Ohr ueberlappt 0,2 mm in die Wand (sauberes Netz), Lippen-Aussparung r=4 → 0,3 mm Luft
module dichtung() {
    difference() {
        union() {
            difference() { rbox(al, ab, dicht_t, 3); translate([-il/2, -ib/2, -1]) cube([il, ib, dicht_t + 2]); }
            for (p=dome()) translate([p[0], p[1], 0]) cylinder(d=ohr_d, h=dicht_t);
            // Wulst auf der Wandmitte (1,5 mm von aussen)
            translate([0,0,dicht_t - 0.01]) difference() {
                rbox(al - 3 + wulst_b, ab - 3 + wulst_b, wulst_h, 1.5 + wulst_b/2);
                translate([0,0,-1]) rbox(al - 3 - wulst_b, ab - 3 - wulst_b, wulst_h + 2, max(0.5, 1.5 - wulst_b/2));
            }
        }
        for (p=dome()) translate([p[0], p[1], -1]) cylinder(d=3.4, h=dicht_t + wulst_h + 2);
    }
}

if (TEIL=="dichtung") dichtung();
// Kollisionspruefung: muss LEER sein (Dichtung auf dem Rand, Deckel darauf)
if (TEIL=="pruef_deckel") intersection() { translate([0,0,ah]) dichtung(); translate([0,0,ah + dicht_t]) deckel(); }
if (TEIL=="pruef_gehaeuse") intersection() { translate([0,0,ah]) dichtung(); gehaeuse(); }
if (TEIL=="gehaeuse") gehaeuse();
if (TEIL=="deckel") rotate([180,0,0]) deckel();     // Druck: Deckelplatte unten
if (TEIL=="alle") { gehaeuse(); translate([0, ab + 30, 0]) rotate([180,0,0]) deckel(); }
if (TEIL=="zusammen") { gehaeuse(); %translate([0,0,boden + ih]) deckel(); }

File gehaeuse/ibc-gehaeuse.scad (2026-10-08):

// IBC-Wasserstand: Halter fuer Ultraschallsensor + Schwimmerschalter, Box fuer den D1 mini
// Stand 04.10.2026 — Notiz project_ibc_wasserstand.  Ueberdacht draussen → PETG reicht.
//
// TEIL = "kombi_gehaeuse" | "kombi_deckel" | "sensor_halter" | "sensor_abdeckung" | "d1_box" | "d1_deckel" | "schwimmer_halter" | "alle"
//
// ALLES MIT ★ VOR DEM DRUCK MESSEN (Masse sind noch nicht bekannt):
//   Sensor: Masse gemessen 07.10.; ★ s_koerper_h (Deutung 12,64) + Flanschgroesse gegen Deckelflaeche pruefen
//   Deckel A: IBC-Oberseite neben der Oeffnung: Ausschnitt 70 x 35 (Flanschfenster unten als Schablone anzeichnen)
//   ★ gewinde_d  Gewindedurchmesser des Schwimmerschalters, ★ haenge_tiefe Schalthoehe unter dem Deckelrand
//   ★ rand_t     Wandstaerke am Einfuellstutzen des Zielcontainers (dort haengt der Schwimmer-Halter ein)

TEIL = "alle";
$fn = 64;

// ---------- Ultraschall-Halter (Deckel von Container A) ----------
// A02YYUW = RECHTECKGEHAEUSE mit zwei Wandlern + zwei Laschen (nicht rund!).
// Gemessen 07.10.2026 (Jens, Messschieber), Datenblatt DFRobot SEN0311: 84,6 x 29,6 x 18,5
s_l      = 63.30;  // Koerper ohne Laschen
s_b      = 29.46;
s_ges_l  = 84.14;  // mit Laschen
s_ges_h  = 18.17;  // Gesamthoehe inkl. Wandler
s_koerper_h = 12.64; // Koerper OHNE Wandler (Jens bestaetigt 07.10.) → Wandler stehen ~5,5 vor
lasche_b = 12;     // ★ aus Foto geschaetzt (~10)
kabel_b  = 11;     // Kabeltuelle mittig an der Laengsseite
spiel    = 0.4;
// Fenster unter dem Koerper: beide Wandler (Ring ~19,5, Abstand ~37 — aus Foto geschaetzt) schauen hindurch,
// der Koerper liegt auf dem umlaufenden Rand. Ein Fenster statt zwei Loechern → Wandlerabstand egal.
fenster_l = 60; fenster_b = 25;
flansch_l = 104; flansch_b = 60; flansch_t = 4;   // Stelle neben der Oeffnung ist eben (Jens 07.10.)
wand = 2.2;
rahmen_h = s_koerper_h - 0.6;  // Abdeckung klemmt den Sensor leicht auf den Rand
ri_l = s_l + 2*spiel; ri_b = s_b + 2*spiel;
ra_l = ri_l + 2*wand; ra_b = ri_b + 2*wand;
dom_d = 8;  dom_pos = [[ra_l/2+1, ra_b/2+1],[-ra_l/2-1, ra_b/2+1],[ra_l/2+1,-ra_b/2-1],[-ra_l/2-1,-ra_b/2-1]];

module rrect(l, b, h, r=3) {
    hull() for (x=[-l/2+r, l/2-r], y=[-b/2+r, b/2-r]) translate([x,y,0]) cylinder(r=r, h=h);
}

module sensor_halter() {
    difference() {
        union() {
            rrect(flansch_l, flansch_b, flansch_t, 5);
            translate([0,0,flansch_t]) rrect(ra_l, ra_b, rahmen_h, 2);
            for (p=dom_pos) translate([p[0],p[1],0]) cylinder(d=dom_d, h=flansch_t + rahmen_h);
        }
        // Sensortasche
        translate([0,0,flansch_t]) rrect(ri_l, ri_b, rahmen_h + 1, 1);
        // Fenster fuer die Wandler, nach unten 45° aufgeweitet (keine Randechos)
        hull() {
            translate([0,0,flansch_t - 0.01]) rrect(fenster_l, fenster_b, 0.02, 2);
            translate([0,0,-0.01]) rrect(fenster_l + 2*flansch_t, fenster_b + 2*flansch_t, 0.02, 2);
        }
        // Aussparungen fuer die Laschen an den Stirnseiten (volle Hoehe, Laschenebene unbekannt)
        for (sx=[-1,1]) translate([sx*(ra_l/2), 0, flansch_t + rahmen_h/2 + 0.01]) cube([wand*3, lasche_b, rahmen_h], center=true);
        // Kabeltuelle (mittig an einer Laengsseite)
        translate([0, ra_b/2, flansch_t + rahmen_h/2 + 0.01]) cube([kabel_b, wand*3, rahmen_h], center=true);
        // Schraubdome: 2,5 mm Vorbohrung fuer Blechschrauben 3 x 16 (Abdeckung)
        for (p=dom_pos) translate([p[0],p[1],flansch_t]) cylinder(d=2.5, h=rahmen_h + 1);
        // 4 Befestigungsloecher M4 in den Deckel (zusaetzlich Silikon/Sikaflex zwischen Flansch und Deckel)
        for (x=[-flansch_l/2+7, flansch_l/2-7], y=[-flansch_b/2+7, flansch_b/2-7]) translate([x,y,-1]) cylinder(d=4.4, h=flansch_t + 2);
    }
}

// Abdeckung: klemmt den Sensor in die Tasche und schuetzt die Rueckseite vor Tropfwasser
module sensor_abdeckung() {
    t = 2.4;
    difference() {
        hull() for (p=dom_pos) translate([p[0],p[1],0]) cylinder(d=dom_d, h=t);
        for (p=dom_pos) translate([p[0],p[1],-1]) cylinder(d=3.4, h=t + 2);
        // Kabeltuelle nicht einklemmen
        translate([0, ra_b/2, 0]) cube([kabel_b, 6, 10], center=true);
    }
}

// ---------- KOMBI-GEHAEUSE: Sensor + D1 mini in einem (07.10.2026) ----------
// Sensorkammer (Fenster nach unten) und D1-Kammer nebeneinander, getrennt durch eine Wand mit Kabelschlitz.
// WICHTIG: Sensor mit einer Silikonraupe auf den Auflagerand setzen → feuchte Tankluft bleibt aus der D1-Kammer.
// Kabel (USB-Strom angeloetet an 5V/G, Schwimmer) durch 2 Verschraubungen M12x1,5 in der Aussenwand.
k_h    = 24;                    // Innenhoehe ueber dem Boden
k_w    = 2.4;                   // Wandstaerke
k_il   = s_ges_l + 2;           // innen Laenge: Sensor MIT Laschen
k_sy0  = -ri_b/2;               // Sensorkammer y-Bereich
k_sy1  =  ri_b/2;
k_ty   = 2.2;                   // Trennwand
k_dy1  = k_sy1 + k_ty + 42;     // D1-Kammer bis hier
k_rand = 10;                    // Flansch rundum (Schrauben in die IBC-Oberseite)
k_m12  = 12.3;
k_m12_wand = 3;   // Wandstaerke an den Verschraubungen
k_dom  = 8;
function k_dome() = [for (x=[-k_il/2-k_w, k_il/2+k_w], y=[k_sy0-k_w, k_dy1+k_w]) [x,y]];

module k_box_aussen(h) {
    hull() {
        translate([-k_il/2-k_w, k_sy0-k_w, 0]) cube([k_il+2*k_w, k_dy1-k_sy0+2*k_w, h]);
        for (p=k_dome()) translate([p[0],p[1],0]) cylinder(d=k_dom, h=h);
    }
}

module kombi_gehaeuse() {
    fx0 = -k_il/2-k_w-k_rand; fx1 = -fx0;
    fy0 = k_sy0-k_w-k_rand;   fy1 = k_dy1+k_w+k_rand;
    difference() {
        union() {
            // Flansch = Boden
            translate([(fx0+fx1)/2, (fy0+fy1)/2, 0]) rrect(fx1-fx0, fy1-fy0, flansch_t, 5);
            translate([0,0,flansch_t]) k_box_aussen(k_h);
        }
        // Innenraum
        translate([-k_il/2, k_sy0, flansch_t]) cube([k_il, k_dy1-k_sy0, k_h+1]);
        // Fenster fuer die Wandler, nach unten 45° aufgeweitet
        hull() {
            translate([0,0,flansch_t - 0.01]) rrect(fenster_l, fenster_b, 0.02, 2);
            translate([0,0,-0.01]) rrect(fenster_l + 2*flansch_t, fenster_b + 2*flansch_t, 0.02, 2);
        }
        // Schraubloecher Deckel (Blechschraube 3 x 16)
        for (p=k_dome()) translate([p[0],p[1],flansch_t+k_h-14]) cylinder(d=2.5, h=15);
        // Befestigung auf dem IBC: 4 x Edelstahl-Blechschraube 4,2 (im IBC 3,2 vorbohren)
        for (x=[fx0+5.5, fx1-5.5], y=[fy0+5.5, fy1-5.5]) translate([x,y,-1]) cylinder(d=4.4, h=flansch_t+2);
        // 2 Kabelverschraubungen M12 in der Aussenwand der D1-Kammer
        for (x=[-22, 22]) translate([x, k_dy1-1, flansch_t+11]) rotate([-90,0,0]) cylinder(d=k_m12, h=k_w+8);   // Wand ist durch die Eckdome ~6,4 dick
        // Innen ausgespart auf k_m12_wand Reststaerke, damit Standard-Verschraubungen (Gewinde 8 mm) samt Mutter fassen
        for (x=[-22, 22]) translate([x, k_dy1-0.01, flansch_t+11]) rotate([-90,0,0]) cylinder(d=22, h=k_w + 4 - k_m12_wand);
        // Belueftung/Kondenswasser: 2-mm-Loch unten in der Stirnwand der D1-Kammer
        translate([k_il/2-1, k_dy1-6, flansch_t+1.2]) rotate([0,90,0]) cylinder(d=2, h=k_w+8);
    }
    // Trennwand mit Kabelschlitz (mittig, fuer die Kabeltuelle des Sensors)
    difference() {
        translate([-k_il/2, k_sy1, flansch_t]) cube([k_il, k_ty, k_h]);
        translate([-kabel_b/2, k_sy1-1, flansch_t+2]) cube([kabel_b, k_ty+2, k_h]);
        // Platz fuer die Deckellippe an beiden Enden
        for (sx=[-1,1]) translate([sx>0 ? k_il/2-2.2 : -k_il/2-0.01, k_sy1-1, flansch_t+k_h-3.6]) cube([2.21, k_ty+2, 4]);
    }
    // Anschlaege an den Sensor-Stirnseiten (Laschen bleiben frei)
    for (sx=[-1,1], sy=[-1,1]) {
        y0 = sy<0 ? k_sy0 : lasche_b/2;
        translate([sx>0 ? ri_l/2 : -ri_l/2-2, y0, flansch_t]) cube([2, ri_b/2 - lasche_b/2, 5]);
    }
    // Auflageleisten fuer den D1 mini (34,2 x 25,6), Platine mit Doppelklebeband/Heisskleber fixieren
    dy0 = k_sy1 + k_ty + 2;
    for (y=[dy0, dy0 + d1_b + 2*d1_spiel - 2]) translate([-(d1_l+2*d1_spiel)/2, y, flansch_t]) cube([d1_l+2*d1_spiel, 2, 3]);
}

module kombi_deckel() {
    t = 2.4; lip_h = 3; lip_w = 1.4; sp = 0.35;
    difference() {
        k_box_aussen(t);
        for (p=k_dome()) translate([p[0],p[1],-1]) cylinder(d=3.4, h=t+2);
    }
    // umlaufende Lippe nach unten (in den Innenraum) gegen Schlagregen — Trennwand bekommt Aussparung
    translate([0,0,-lip_h]) difference() {
        translate([-k_il/2+sp, k_sy0+sp, 0]) cube([k_il-2*sp, k_dy1-k_sy0-2*sp, lip_h]);
        translate([-k_il/2+sp+lip_w, k_sy0+sp+lip_w, -1]) cube([k_il-2*sp-2*lip_w, k_dy1-k_sy0-2*sp-2*lip_w, lip_h+2]);
    }
    // zwei Druckrippen auf den Sensorruecken (0,4 mm Vorspannung)
    rippe = k_h - s_koerper_h + 0.4;
    for (x=[-20, 20]) translate([x-1, -ri_b/2+3, -rippe]) cube([2, ri_b-6, rippe]);
}
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

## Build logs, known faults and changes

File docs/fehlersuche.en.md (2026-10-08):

🇩🇪 [Deutsche Version](fehlersuche.md)

# Troubleshooting

Back to the [README](../README.en.md). Known failure patterns from the project history (04.–08.10.2026). Items that are only described as a precaution are marked *(precautionary)*.

## Node A (`ibc-wasser`)

| Symptom | Cause | Solution |
|---|---|---|
| `Zielcontainer voll` (target container full) on A is permanently **on** | The float input GPIO14 is open (internal pull-up). The float has been at node B since 07.10. | Delete the `binary_sensor` block from the Builder YAML A and remove the orphaned entity in HA |
| Fill level jumps or shows nonsense when the container is almost empty *(precautionary)* | 60° sound cone: echoes from the wall, the pump riser pipe or the corrugated hose | Location ≥ 30 cm from the pump and ≥ 20 cm from the wall; the median filter (15) catches isolated echoes |
| No value / `nan` with a very full container | The sensor is blind below ~30 mm | That is why 100 % is at 50 mm. From 97 % a push is sent |
| Sensor delivers different data / values only on request | The yellow wire (RX/mode) is connected to ground | leave yellow unconnected |
| Fill level does not match the folding rule | Empty value wrong, bottom uneven *(unverified)*, folding rule at an angle | recalibrate, see [einmessen.en.md](einmessen.en.md) |
| Moisture in the D1 chamber *(precautionary)* | Tank air through the cable slot of the partition wall or past the sensor | Silicone bead under the sensor and in the slot; keep the 2 mm condensation hole clear |
| Water at the sensor flange | A is brim-full because there is no overflow | Sealing tape under the flange; HA reports from 97 % |
| Gland does not grip | The printed wall at the M12 is 6.4 mm thick (2nd revision) | Thread the nut on the inside as far as possible, secure with hot glue; or counterbore Ø 22–25 on the inside; or reprint the current STL (3 mm remaining wall) |

## Node B (`ibc-b`)

| Symptom | Cause | Solution |
|---|---|---|
| Node **never** wakes up after deep sleep | D0–RST jumper missing or without contact | Check the jumper; until then only the reset button helps |
| Flashing via USB fails | The D0–RST jumper interferes with auto-reset | Briefly remove the jumper |
| Node only reports every 2 h | Battery < 3.3 V, or A0 unconnected (07.10.: 0.01 V) or without battery (08.10.: 0.41 V) | Check battery/divider; after a reset it is awake for 10 min |
| OTA update does not arrive | The node is asleep | Switch on `IBC B wach halten` (keep awake) in HA, wait up to 15 min (or 2 h), flash, then switch **off** again |
| Battery drains quickly | "Keep awake" forgotten; shield quiescent current too high (bad batch with SW6115/IP3005A: ~100 mA instead of ~0.3 mA); panel shaded | Helper off; look at the battery curve in HA; replace the shield; clean and align the panel |
| D1 mini starts unreliably *(precautionary)* | powered from the shield's 3V output (XC6206 without capacitor) | always shield **5V** → D1 **5V** |
| Shield input destroyed *(precautionary)* | Panel open-circuit voltage up to 8.2 V > 6.5 V input limit | Zener diode 6.2 V in parallel, ring to + |
| Smoke/heat when inserting the battery *(precautionary)* | Holder polarity reversed (known layout error of this shield series) | measure first: + beeps at coil 3R3. Checked on both existing shields ✔ |
| Strange behaviour during testing | D1 USB and shield connected at the same time | **never** both at the same time |
| `Zielcontainer voll` = on although B is empty | Float cable detached/open or float mounted the wrong way round | Check the cable; arrow on the float, rotate by 180° (do **not** invert the firmware) |
| Hotspot password or API key wrong after flashing | A test build with dummy secrets was flashed (`esphome upload` does not recompile) | always `esphome run` with real secrets; then verify via the API |
| Battery does not charge in winter *(precautionary)* | Li-ion must not be charged below 0 °C | open. According to the notes the charger has no temperature monitoring *(not confirmed)* |

## Pump / Home Assistant

| Symptom | Cause | Solution |
|---|---|---|
| A > 90 %, but the pump does not start immediately | **Intentional:** start only when B has reported freshly (< 120 s), i.e. at the next wake-up (≤ 15 min) | wait; otherwise check lock, "target full" and B's sign of life |
| Pump does not start at all any more | `IBC-Pumpe gesperrt` (IBC pump locked) is on (after dry run or 30 min) | Inspect the cause on site, then switch off the lock **manually** |
| Push "Pumpe gesperrt – Leistung zu niedrig" (pump locked – power too low), although everything was pumped | The threshold `below: 20` is still a placeholder | set it to ~60 % of the normal power |
| Push "A sinkt nicht" (A is not dropping) | Line blocked, pump drawing air, ball valve closed; or the pump delivers less than ~2 l/min | Check line and valve; adjust the rule if necessary |
| Push "Knoten B meldet sich nicht" (node B is not reporting) | Battery empty, Wi-Fi, node stuck in deep sleep without D0–RST | Battery/panel, Wi-Fi signal, reset |
| Pump starts after a power failure *(precautionary)* | Power-outage memory of the plug not `off` | set to `off` (configured this way since 07.10.) |
| Plug `unavailable` | It is unplugged (since 07.10. 18:33), or there is no Zigbee reception | plug it in; check reception at the location |

## Ordering / parts

| Problem | Note |
|---|---|
| Seki M12 has the wrong colour | The listings are mixed up: B083V943WD is **grey** despite "black" in the title; B083V8V9TR was chosen. Its description also says "grau (RAL7035)" (grey), so please check the delivery |
| Lapp SKINTOP ST-M M12 does not seal the float cable | Clamping range starts at 3.5 mm, the float cable is ~3 mm. Hence types with 3–6.5 mm |
| Panel with 6 V nominal voltage | unsuitable (open-circuit ~7.7 V). Only 5 V / 5.5 V panels with Zener diode |

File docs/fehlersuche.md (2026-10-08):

🇬🇧 [English version](fehlersuche.en.md)

# Fehlersuche

Zurück zur [README](../README.md). Bekannte Fehlerbilder aus dem Projektverlauf (04.–08.10.2026). Was nur vorbeugend beschrieben ist, steht als *(vorbeugend)* da.

## Knoten A (`ibc-wasser`)

| Fehlerbild | Ursache | Lösung |
|---|---|---|
| `Zielcontainer voll` an A ist dauernd **an** | Der Schwimmereingang GPIO14 ist offen (interner Pull-up). Der Schwimmer sitzt seit 07.10. an Knoten B | Den `binary_sensor`-Block aus der Builder-YAML A löschen und die verwaiste Entität in HA entfernen |
| Füllstand springt oder zeigt bei fast leerem Container Unsinn *(vorbeugend)* | 60°-Schallkegel: Echos von Wand, Steigrohr der Pumpe oder Wellschlauch | Stelle ≥ 30 cm von der Pumpe und ≥ 20 cm von der Wand; der Medianfilter (15) fängt Einzelechos ab |
| Kein Wert / `nan` bei sehr vollem Container | Der Sensor ist unter ~30 mm blind | 100 % liegt deshalb bei 50 mm. Ab 97 % kommt ein Push |
| Sensor liefert andere Daten / Werte nur auf Anforderung | Die gelbe Ader (RX/Modus) liegt auf Masse | gelb frei lassen |
| Füllstand stimmt nicht mit dem Zollstock überein | Leerwert falsch, Boden uneben *(ungeprüft)*, Zollstock schräg | neu einmessen, siehe [einmessen.md](einmessen.md) |
| Feuchtigkeit in der D1-Kammer *(vorbeugend)* | Tankluft durch den Kabelschlitz der Trennwand oder am Sensor vorbei | Silikonraupe unter dem Sensor und im Schlitz; 2-mm-Kondenswasserloch frei halten |
| Wasser am Sensorflansch | A ist randvoll, weil kein Überlauf vorhanden ist | Dichtband unter dem Flansch; HA meldet ab 97 % |
| Verschraubung fasst nicht | Die gedruckte Wand ist an den M12 6,4 mm dick (2. Fassung) | Mutter innen so weit es geht aufdrehen, mit Heißkleber sichern; oder innen Ø 22–25 aussenken; oder Neudruck der aktuellen STL (3 mm Restwand) |

## Knoten B (`ibc-b`)

| Fehlerbild | Ursache | Lösung |
|---|---|---|
| Knoten wacht nach dem Tiefschlaf **nie** auf | D0–RST-Brücke fehlt oder hat keinen Kontakt | Brücke prüfen; bis dahin hilft nur die Reset-Taste |
| Flashen per USB scheitert | Die D0–RST-Brücke stört den Auto-Reset | Brücke kurz abziehen |
| Knoten meldet sich nur alle 2 h | Akku < 3,3 V, oder A0 unbeschaltet (07.10.: 0,01 V) bzw. ohne Akku (08.10.: 0,41 V) | Akku/Teiler prüfen; nach Reset ist er 10 min wach |
| OTA-Update kommt nicht an | Der Knoten schläft | In HA `IBC B wach halten` an, bis zu 15 min (bzw. 2 h) warten, flashen, danach wieder **aus** |
| Akku leert sich schnell | „wach halten“ vergessen; Ruhestrom des Shields zu hoch (schlechte Charge mit SW6115/IP3005A: ~100 mA statt ~0,3 mA); Panel verschattet | Helfer aus; Akkuverlauf in HA ansehen; Shield tauschen; Panel reinigen und ausrichten |
| D1 mini startet unzuverlässig *(vorbeugend)* | vom 3V-Ausgang des Shields versorgt (XC6206 ohne Kondensator) | immer Shield **5V** → D1 **5V** |
| Shield-Eingang zerstört *(vorbeugend)* | Leerlaufspannung des Panels bis 8,2 V > 6,5 V Eingangsgrenze | Z-Diode 6,2 V parallel, Ring an + |
| Rauch/Wärme beim Akku-Einlegen *(vorbeugend)* | Halterpolung vertauscht (bekannter Layoutfehler dieser Shield-Serie) | vorher messen: + piept an Spule 3R3. Bei den beiden vorhandenen geprüft ✔ |
| Komisches Verhalten beim Testen | D1-USB und Shield gleichzeitig angeschlossen | **niemals** beides gleichzeitig |
| `Zielcontainer voll` = an, obwohl B leer ist | Schwimmerkabel ab/offen oder Schwimmer falsch herum eingebaut | Kabel prüfen; Pfeil am Schwimmer, um 180° drehen (Firmware **nicht** invertieren) |
| Hotspot-Passwort oder API-Schlüssel stimmt nach dem Flashen nicht | Ein Prüfbuild mit Dummy-Secrets wurde geflasht (`esphome upload` kompiliert nicht neu) | immer `esphome run` mit echten Secrets; danach API-Gegenprobe |
| Akku lädt im Winter nicht *(vorbeugend)* | Li-Ion darf unter 0 °C nicht geladen werden | offen. Der Lader hat laut Notizen keine Temperaturüberwachung *(nicht belegt)* |

## Pumpe / Home Assistant

| Fehlerbild | Ursache | Lösung |
|---|---|---|
| A > 90 %, aber Pumpe startet nicht sofort | **Absicht:** Start erst, wenn B sich frisch gemeldet hat (< 120 s), also beim nächsten Aufwachen (≤ 15 min) | abwarten; sonst Sperre, „Ziel voll“ und Lebenszeichen von B prüfen |
| Pumpe startet gar nicht mehr | `IBC-Pumpe gesperrt` ist an (nach Trockenlauf oder 30 min) | Ursache vor Ort ansehen, dann die Sperre **von Hand** ausschalten |
| Push „Pumpe gesperrt – Leistung zu niedrig“, obwohl alles gefördert hat | Die Schwelle `below: 20` ist noch ein Platzhalter | auf ~60 % der Normalleistung setzen |
| Push „A sinkt nicht“ | Leitung zu, Pumpe zieht Luft, Kugelhahn zu; oder die Pumpe fördert weniger als ~2 l/min | Leitung und Hahn prüfen; ggf. Regel anpassen |
| Push „Knoten B meldet sich nicht“ | Akku leer, WLAN, Knoten hängt im Tiefschlaf ohne D0–RST | Akku/Panel, WLAN-Signal, Reset |
| Pumpe läuft nach Stromausfall an *(vorbeugend)* | Power-outage-memory der Steckdose nicht `off` | auf `off` setzen (seit 07.10. so eingestellt) |
| Steckdose `unavailable` | Sie ist ausgesteckt (seit 07.10. 18:33), oder es gibt keinen Zigbee-Empfang | einstecken; Empfang am Standort prüfen |

## Bestellung / Teile

| Problem | Hinweis |
|---|---|
| Seki-M12 hat falsche Farbe | Die Angebote sind vertauscht: B083V943WD ist trotz „schwarz“ im Titel **grau**, gewählt wurde B083V8V9TR. Auch dort steht in der Beschreibung „grau (RAL7035)“, die Lieferung bitte prüfen |
| Lapp SKINTOP ST-M M12 dichtet das Schwimmerkabel nicht | Klemmbereich erst ab 3,5 mm, das Schwimmerkabel hat ~3 mm. Deshalb Typen mit 3–6,5 mm |
| Panel mit 6 V Nennspannung | ungeeignet (Leerlauf ~7,7 V). Nur 5-V-/5,5-V-Panels mit Z-Diode |

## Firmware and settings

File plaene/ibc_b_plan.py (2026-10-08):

import matplotlib; matplotlib.use("Agg")
import matplotlib.pyplot as plt
from matplotlib.patches import Rectangle, Circle, Polygon
import sys
fig = plt.figure(figsize=(8.27, 11.69)); ax = fig.add_axes((0.0,0.0,1.0,1.0)); ax.set_xlim(0,210); ax.set_ylim(0,297); ax.axis("off")
L=dict(color="black", lw=1.4)
def line(*p, **k): ax.plot([a[0] for a in p],[a[1] for a in p], **{**L, **k})
def dot(x,y,c="black"): ax.add_patch(Circle((x,y),0.9,color=c))
T=lambda x,y,s,**k: ax.text(x,y,s,**{"fontsize":9,**k})
def box(x,y,w,h,titel):
    ax.add_patch(Rectangle((x,y),w,h,fill=False,lw=1.5)); T(x+w/2,y+h+2,titel,ha="center",fontsize=9.5,fontweight="bold")
def widerstand(x,y1,y2,name):   # senkrecht
    m=(y1+y2)/2; line((x,y1),(x,m+5)); line((x,m-5),(x,y2)); ax.add_patch(Rectangle((x-1.8,m-5),3.6,10,fill=False,lw=1.3)); T(x+3,m-1,name,fontsize=8,fontweight="bold")

T(15,282,"IBC Container B – Solar-Knoten – Schaltplan",fontsize=18,fontweight="bold")
T(15,274,"Wemos D1 mini (ESP8266) · 18650 Battery Shield V3 (rechtes, ohne USB-Buchse) · Schwimmer „Ziel voll“ · Stand 07.10.2026",fontsize=8.5)

# Panel
px,py=8,215
box(px,py,30,24,"Solarpanel 1 W")
T(px+2,py+15,"Seeed 5,5 V / 170 mA",fontsize=7.5); T(px+2,py+9,"Leerlauf bis 8,2 V!",fontsize=7.5,color="firebrick")
T(px+2,py+3,"außen am Schuppen",fontsize=7.5,color="dimgray")
T(px+31,py+19,"+",fontsize=11,fontweight="bold"); T(px+31,py+3,"−",fontsize=11,fontweight="bold")
line((px+30,py+18),(70,py+18),color="firebrick",lw=1.8); line((px+30,py+5),(70,py+5),lw=1.8)
T(40,py+21,"2–3 m Kabel, M12-Verschr.",fontsize=7,color="dimgray")
# Z-Diode
zx=62
dot(zx,py+18,"firebrick"); dot(zx,py+5)
line((zx,py+18),(zx,py+14)); line((zx,py+9),(zx,py+5))
ax.add_patch(Polygon([(zx-3,py+9),(zx+3,py+9),(zx,py+13.5)],closed=True,fill=False,lw=1.3))
line((zx-3,py+13.6),(zx+3,py+13.6)); line((zx-3,py+13.6),(zx-4,py+12.4)); line((zx+3,py+13.6),(zx+4,py+14.8))
T(zx-22,py-7,"Z-Diode BZX85C6V2",fontsize=7.5,fontweight="bold"); T(zx-22,py-11,"parallel, Ring (Kathode) → +",fontsize=7)

# Shield
sx,sy,sw,sh=70,170,55,70
box(sx,sy,sw,sh,"18650 Battery Shield V3")
T(sx+2,py+18,"Input +",fontsize=8.5,fontweight="bold"); T(sx+2,py+5,"Input −",fontsize=8.5,fontweight="bold")
T(sx+2,py+11.5,"(Pads der fehlenden\nUSB-Buchse U1)",fontsize=6.5,color="dimgray")
ax.add_patch(Rectangle((sx+8,sy+16),38,12,fill=False,lw=1.2,ls="--")); T(sx+12,sy+21,"Akku EVE 18650-33V",fontsize=7.5)
T(sx+12,sy+30,"+ (Halterkontakt)",fontsize=7.5,fontweight="bold",color="firebrick")
T(sx+3,sy+5,"Lader TC4056 · Schutz DW01+8205\nBoost 5 V (läuft immer)",fontsize=6.8,color="dimgray")
for n,y in (("5V",232),("GND",222)): T(sx+sw-2,y,n,ha="right",fontsize=9,fontweight="bold")

# D1 mini
dx,dy,dw,dh=150,140,40,100
box(dx,dy,dw,dh,"Wemos D1 mini")
pins={"5V":232,"G":222,"A0":205,"D0":190,"RST":180,"D5":160}
for n,y in pins.items(): T(dx+2,y,n,fontsize=9,fontweight="bold")
T(dx+2,dy+4,"Antennenende nach oben\n(weg von Akku/Käfig)",fontsize=6.8,color="dimgray")

# 5V / GND
line((sx+sw,232),(dx,232),color="darkorange",lw=1.8); T(sx+sw+3,234,"5 V",color="darkorange",fontsize=8,fontweight="bold")
line((sx+sw,222),(dx,222),lw=1.8); T(sx+sw+3,224,"GND",fontsize=8,fontweight="bold")
# Akku-Messung
ax_=sx+30
line((ax_,sy+29),(ax_,sy-8),(138,sy-8),(138,205-12))
widerstand(138,205-12,205,"")
T(113,196,"100 k + 22 kΩ",fontsize=8,fontweight="bold")
line((138,205),(dx,205),color="purple",lw=1.5); dot(ax_,sy+29,"firebrick")
T(72,150,"Akku + direkt vom Halterkontakt\n(Draht anlöten) → 100 kΩ + 22 kΩ in Reihe → A0",fontsize=7,color="purple")
# D0-RST
line((dx-6,190),(dx,190)); line((dx-6,180),(dx,180)); line((dx-6,190),(dx-6,180),color="teal",lw=1.8)
T(dx-30,184,"Draht D0–RST\n(Tiefschlaf)",fontsize=7,color="teal",fontweight="bold")
# Schwimmer
fx,fy=105,128
line((dx,160),(fx+30,160),(fx+30,fy+6)); line((fx+30,fy-6),(fx+30,fy-14),(dx+20,fy-14),(dx+20,dy)); dot(dx+20,dy)
T(dx+22,dy-6,"G",fontsize=8,fontweight="bold")
line((fx+30,fy+6),(fx+26,fy-3)); dot(fx+30,fy+6); dot(fx+30,fy-6)
T(fx-38,fy+3,"Schwimmerschalter in B",fontsize=8.5,fontweight="bold"); T(fx-38,fy-3,"Einbau: öffnet bei Wasser",fontsize=7.5)
T(fx-38,fy-8,"(Kabelbruch = „voll“ = Pumpe gesperrt)",fontsize=7,color="dimgray")
T(fx-38,fy-13,"M12-Verschraubung",fontsize=7.5,color="dimgray")

T(15,100,"Hinweise",fontsize=11,fontweight="bold")
H=[
"• Z-Diode PARALLEL an den Eingang, Ring (Kathode) an +. Ohne sie liegt bei vollem Akku die Leerlaufspannung des Panels",
"   (bis 8,2 V) am Eingang – das Shield verträgt laut Händler nur 6,5 V.",
"• Panel an die Pads der fehlenden USB-Buchse U1 (VBUS = +, GND = −). Vor dem Löten Foto der Pads an Claude: welches Pad ist VBUS.",
"• Akku erst einlegen, wenn alles verdrahtet ist; Polung am Halter ist geprüft (Aufdruck stimmt, 07.10.).",
"• D1 mini über den 5-V-Pin versorgen (Boost des Shields). Der 3-V-Ausgang des Shields ist ohne Kondensator instabil – NICHT nehmen.",
"• A0: Der D1 mini hat intern 220 kΩ/100 kΩ (3,2 V Endwert); mit 100 kΩ + 22 kΩ in Reihe davor (= 122 kΩ) misst er bis ~4,4 V. Dauerstrom ~10 µA.",
"• D0–RST-Draht ist für den Tiefschlaf nötig. Klappt das Flashen per USB nicht, den Draht kurz abziehen.",
"• Schwimmer an D5 (GPIO14) und G, interner Pull-up. Geschlossen = Wasser unten, offen = B voll ODER Kabel ab → Pumpe gesperrt.",
"• Verbrauch (geschätzt): Shield ~0,3 mA + D1 im Schlaf ~0,2 mA + 96× Aufwachen ≈ 25 mAh/Tag → EVE 3200 mAh ≈ 4 Monate ohne Sonne.",
"• Zum Aktualisieren (OTA) in HA „IBC B wach halten“ einschalten und auf das nächste Aufwachen warten (max. 15 min).",
]
for i,s in enumerate(H): T(15,92-i*6.3,s,fontsize=7.6)

out = sys.argv[1] if len(sys.argv)>1 else "ibc-b-schaltplan.pdf"
fig.savefig(out)
if len(sys.argv)>2: fig.savefig(sys.argv[2],dpi=80)

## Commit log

2026-10-08 Initial commit: firmware, plans, enclosures and documentation (DE/EN)
    [ibc-b-gehaeuse.scad, ibc-gehaeuse.scad, ibc_b_deckel.stl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]
2026-10-09 Deckeldichtung (TPU) für Knoten B, Stückliste und Doku DE/EN
    Neues Teil TEIL="dichtung" im SCAD samt Kollisions-Prüfteilen (pruef_deckel,
    pruef_gehaeuse) und gehaeuse/ibc_b_dichtung.stl. Stückliste: Deckelschrauben
    3 x 12 (Blech- oder Spanplattenschraube), Dichtung TPU 95A bzw. EPDM-Band.
    Warnung vor essigvernetzendem Silikon, Verlauf 09.10.
    Closes #1
    [ibc-b-gehaeuse.scad, ibc_b_dichtung.stl]
2026-10-09 Firmware A: Vollstand 50 mm statt 80 mm (kein Überlauf)
    IBC A hat keinen Überlauf → 100 % = 50 mm unter der Oberseite (Sensor < 30 mm blind).
    Builder-Fassung am 09.10.2026 nachgezogen; wirkt beim Einmessen.
    Closes #3
2026-10-11 IBC: Stand 10./11.10. — Schwimmer aus A entfernt, Neustart-Grund an A, B mit fester IP am Standort
    - firmware/ibc-wasser.yaml: Schwimmer-Eingang raus (10.10.), debug mit Neustart-Grund + freiem Speicher (11.10.)
    - firmware/ibc-b.yaml: power_save_mode none, DHCP-Test zurueckgenommen (feste IP)
    - README (DE/EN): Status, Entitaeten, offene Punkte nachgezogen
    - docs/verlauf + fehlersuche (DE/EN): 10./11.10., Fehlerbild haeufige Neustarts A
    Fixes #5
2026-10-13 Doku: Stand 12./13.10. — Pumpenlogik live, Schwimmertest B, Netzteiltausch A
    - ha/ibc-pumpe.yaml: Kopf mit den Abweichungen der Live-Fassung (UI-Helfer +
    10 UI-Automationen seit 12.10.), Datei ist nur noch Referenz; Zigbee-IEEE-Adresse entfernt
    - README DE/EN: Stand 13.10., Statustabelle (Pumpenlogik aktiv, Schwelle 20 W vorlaeufig,
    Probelauf 14.10. 17:30; Schwimmertest B bestanden; 14 Watchdog-Neustarts A,
    Netzteiltausch 13.10. 17:47, Auswertung 14.10. 18:00), Abschnitt 8 nach der Live-Fassung,
    offene Punkte mit Terminen, Entitaeten garten_ibc_wasser_*, abstand_voll_mm 50, Druckstatus B
    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
2026-10-14 Docs: pump test run 14.10. — 175 W normal, dry-run threshold 105 W
    Fixes #9
2026-10-14 Firmware A: logger on UART1 so the sensor uses hardware UART0; debug sensors
    Fixes #13
2026-10-15 Docs: node A reboots solved by hardware UART
    0 reboots in 21.3 h since the hardware-UART flash (before ~0.7/h).
    Fixes #15
2026-10-22 Solar panel holder for node B; update solar build status
    Adds the wall-mounted holder (wedge, frame with slide-in groove, latch)
    with SCAD source, STLs and a preview. README (DE/EN): panel, Zener diode
    and EVE cell delivered and installed on 21.10., wiring as actually
    soldered, enclosure section, open items. Charging is not proven yet.
    Fixes #17
